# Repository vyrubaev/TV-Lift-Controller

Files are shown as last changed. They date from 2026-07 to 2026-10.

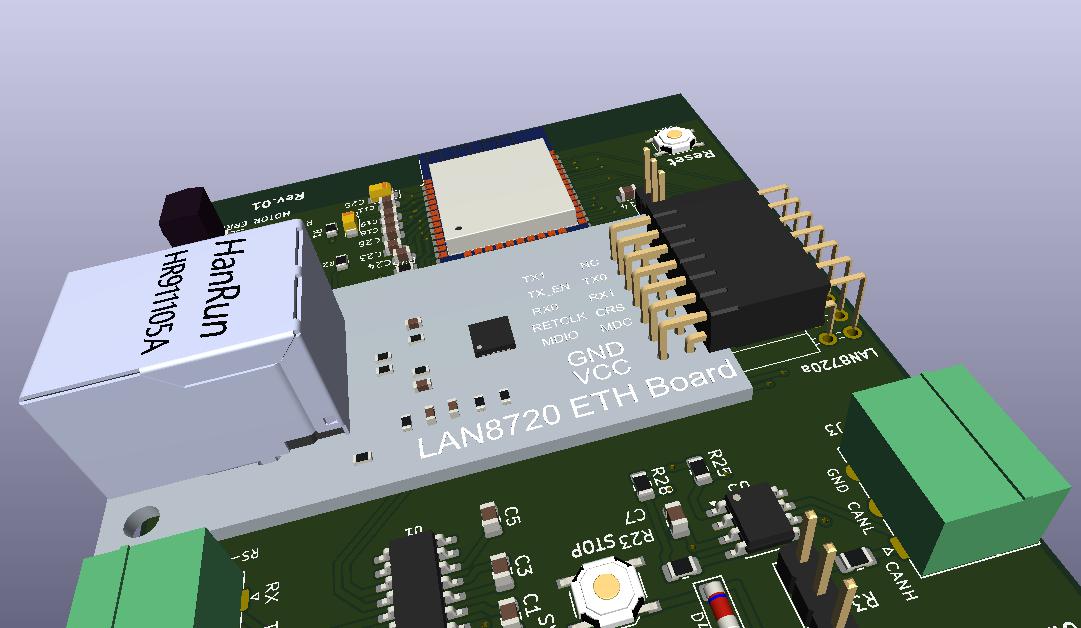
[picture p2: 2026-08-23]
images/network plate.jpg

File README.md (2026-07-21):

# TVLift Controller

Профессиональная платформа управления лифтом для телевизора на базе ESP32.

Проект включает в себя:

- прошивку контроллера ESP32;
- мобильное приложение;
- сервер обновлений и управления;
- веб-панель администратора;
- аппаратную документацию;
- систему удаленного обновления прошивки (OTA — Over-the-Air);
- полную инженерную документацию.

---

# Основные возможности

- управление электроприводом лифта;
- поддержка Wi-Fi и Ethernet;
- первоначальная настройка через Captive Portal;
- безопасное удаленное обновление прошивки;
- хранение настроек во Flash памяти;
- REST API для мобильного приложения;
- журнал событий;
- диагностика устройства;
- поддержка нескольких аппаратных ревизий.

---

# Архитектура проекта

```
TVLift/

├── docs/               Документация
├── firmware/           Прошивка ESP32
├── backend/            Сервер
├── mobile/             Мобильное приложение
├── web-admin/          Панель администратора
├── hardware/           KiCad (схемы и PCB)
├── tools/              Скрипты и утилиты
├── component-library/  Библиотека компонентов
└── README.md
```

---

# Документация

## Архитектура

| Документ | Назначение |
|---|---|
| 00_ProjectVision.md | Цели проекта |
| 01_SystemArchitecture.md | Общая архитектура |
| 02_FirmwareArchitecture.md | Архитектура прошивки |
| 03_StateMachine.md | Конечный автомат |
| 04_API.md | REST API |
| 05_OTA.md | Система обновлений |

---

## Аппаратная часть

| Документ | Назначение |
|---|---|
| Board.md | Описание платы |
| Pinout.md | Назначение выводов |
| Power.md | Система питания |

---

## Библиотека компонентов

В проекте используется собственная библиотека утвержденных компонентов.

Все новые устройства должны использовать компоненты из этой библиотеки, если нет технической причины выбрать другой элемент.

---

# Используемые технологии

## Firmware

- ESP32
- ESP-IDF
- PlatformIO
- C++17

## Backend

- Python
- FastAPI
- PostgreSQL

## Mobile

- Flutter

## Web

- React
- TypeScript

---

# Основные принципы разработки

Проект строится по следующим правилам:

- модульная архитектура;
- минимальная связанность модулей;
- отсутствие глобальных переменных;
- отсутствие динамического выделения памяти в рабочем режиме;
- аппаратная независимость бизнес-логики;
- документирование всех архитектурных решений;
- обязательное код-ревью перед слиянием изменений.

---

# Структура прошивки

Firmware состоит из независимых модулей.

- Boot
- Configuration
- Storage
- Hardware Abstraction Layer (HAL)
- Network Manager
- OTA Manager
- REST API
- Elevator Controller
- Logger
- Diagnostics

---

# Состояния контроллера

Boot

↓

Hardware Init

↓

Load Configuration

↓

Network Connection

↓

Cloud Connection

↓

Ready

↓

Working

↓

Error Recovery

---

# Требования к качеству

- единый стиль кода;
- обязательное документирование публичных интерфейсов;
- отсутствие магических чисел;
- отсутствие дублирования кода;
- обязательные журналы ошибок;
- возможность безопасного восстановления после сбоя.

---

# Версионирование

Используется Semantic Versioning.

MAJOR.MINOR.PATCH

Например

2.4.15

---

# Лицензия

Определяется владельцем проекта.

---

# Статус проекта

🚧 В активной разработке.

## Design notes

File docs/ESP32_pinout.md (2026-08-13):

ESP32-WROOM-32 — карта выводов

**Плата:** TV Lift Controller REV_A  
**Модуль:** ESP32-WROOM-32  
**Источник истины для прошивки:** `BoardConfig`

## Назначение GPIO

| GPIO | Направление | Назначение | Примечание |
|---:|---|---|---|
| 0 | вход | `ETH_RETCLK` | Вход внешнего RMII REF_CLK 50 МГц; strapping-пин. PHY не должен выдавать clock до завершения boot. |
| 1 | выход | `UART_TX_PIN` | UART0 TX / RS-232. Используется также для загрузочных сообщений. |
| 2 | выход | `IR_TRANSMITTER` | Strapping-пин; не подтягивать к +3.3 V при reset. |
| 3 | вход | `UART_RX_PIN` | UART0 RX / RS-232. |
| 4 | вход | `LIMIT_SWITCH_UP_PIN` | Верхний концевик. Обрабатывать аппаратным GPIO-прерыванием. |
| 5 | выход | `CAN_TX_PIN` | Strapping-пин, внешняя подтяжка к +3.3 V допустима и соответствует штатному уровню `1`. |
| 12 | выход | `MOTOR1_PWM` | Strapping-пин MTDI. Во время reset должен оставаться `0`; запрещена внешняя подтяжка к +3.3 V. |
| 13 | вход | `LIMIT_SWITCH_DOWN_PIN` | Нижний концевик. Обрабатывать аппаратным GPIO-прерыванием. |
| 14 | вход | `IR_RECEIVER` | Вход ИК-приёмника. |
| 15 | вход | `CAN_RX_PIN` | Strapping-пин MTDO, внешняя подтяжка к +3.3 V допустима и соответствует штатному уровню `1`. |
| 16 | выход | `MOTOR1_INA` | Направление A драйвера VNH5019. |
| 17 | выход | `MOTOR1_INB` | Направление B драйвера VNH5019. |
| 18 | выход | `ETH_MDIO` | RMII MDIO. |
| 19 | выход | `ETH_TX0` | RMII TXD0. |
| 21 | выход | `ETH_TX_EN` | RMII TX_EN. |
| 22 | выход | `ETH_TX1` | RMII TXD1. |
| 23 | выход | `ETH_MDC` | RMII MDC. |
| 25 | вход | `ETH_RX0` | RMII RXD0. |
| 26 | вход | `ETH_RX1` | RMII RXD1. |
| 27 | вход | `ETH_CRS_DV` | RMII CRS_DV. |
| 32 | вход, ADC | `MOTOR1_CURR_SENS` | Измерение тока двигателя. |
| 33 | вход | `MOTOR1_DIAG` | Авария драйвера VNH5019. Обрабатывать GPIO-прерыванием. |
| 34 | вход | `DRY_CONTACT_DOWN_PIN` | Выход оптопары сухого контакта «вниз». Только вход, внутренней подтяжки нет. |
| 35 | вход | `DRY_CONTACT_UP_PIN` | Выход оптопары сухого контакта «вверх». Только вход, внутренней подтяжки нет. |
| 36 | вход | `ENC_A` | Канал A энкодера. Только вход. |
| 39 | вход | `ENC_B` | Канал B энкодера. Только вход. |

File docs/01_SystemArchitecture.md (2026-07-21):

                  +----------------------+
                  |      Application     |
                  |  (логика устройства) |
                  +----------+-----------+
                             |
      +----------+-----------+-----------+----------+
      |          |           |           |          |
+-----v----+ +---v----+ +----v----+ +----v----+ +---v----+
| Elevator | |Network | | Storage | |   OTA   | | Logger |
+----------+ +--------+ +---------+ +---------+ +--------+
      |           |           |           |
      +-----------+-----------+-----------+
                      |
              +-------v--------+
              |      HAL       |
              | Hardware Layer |
              +-------+--------+
                      |
         +------------+-------------+
         | GPIO I²C SPI UART CAN IR |
         +--------------------------+

---

Полная карта модулей прошивки V.1

Application
│
├── System
│   ├── BootManager
│   ├── TaskManager
│   ├── Watchdog
│   ├── TimeService
│   └── EventBus
│
├── Configuration
│   ├── ConfigManager
│   ├── DeviceConfig
│   ├── NetworkConfig
│   └── UserConfig
│
├── Storage
│   ├── NVS
│   ├── LittleFS
│   └── Backup
│
├── Network
│   ├── NetworkManager
│   ├── WiFiManager
│   ├── EthernetManager
│   ├── DNS
│   ├── DHCP
│   ├── HTTP Client
│   ├── HTTPS Client
│   ├── WebServer
│   └── CaptivePortal
│
├── OTA
│   ├── UpdateManager
│   ├── FirmwareDownloader
│   ├── FirmwareVerifier
│   └── RollbackManager
│
├── Security
│   ├── TLS
│   ├── Certificates
│   ├── DeviceIdentity
│   └── Authentication
│
├── API
│   ├── REST API
│   ├── JSON
│   └── API Dispatcher
│
├── Logger
│   ├── Console
│   ├── FlashLog
│   └── RemoteLog
│
├── Diagnostics
│   ├── SelfTest
│   ├── Statistics
│   ├── MemoryMonitor
│   └── CrashReporter
│
├── Elevator
│   ├── LiftController
│   ├── MotorController
│   ├── SafetyController
│   ├── Calibration
│   ├── Inputs
│   ├── Outputs
│   ├── Position
│   └── Limits
│
└── HAL
    ├── GPIO
    ├── ADC
    ├── PWM
    ├── Timers
    ├── UART
    ├── SPI
    ├── I2C
    ├── CAN
    ├── IR
    ├── Ethernet
    ├── WiFi
    ├── Flash
    └── RTC

    ---

    Полная карта модулей прошивки V.2

    Application
│
├── Core
│
├── Config
│
├── Network
│
├── OTA
│
├── API
│
├── Logger
│
├── Elevator
│
├── Drivers
│
└── HAL

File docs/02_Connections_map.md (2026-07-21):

GPIO5:
    Function:
    Motor Driver Diagnostic Input

    Boot requirement:
    Must be HIGH during reset

    External pull-up required

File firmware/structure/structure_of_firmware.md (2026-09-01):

src/

├── main.cpp

├── Core/
│   ├── Core.h
│   └── Core.cpp

├── Config/
│   ├── BoardConfig.h
│   └── DeviceConfig.h

├── Logger/
│   ├── Logger.h
│   └── Logger.cpp

├── Elevator/
│   ├── Elevator.h
│   └── Elevator.cpp

├── Drivers/
│   ├── Motor.h
│   └── Motor.cpp

├── Network/
│
├── OTA/
|
│
└── API/

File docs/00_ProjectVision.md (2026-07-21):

# TVLift Controller

# Project Vision

**Версия документа:** 1.0

**Статус:** Draft

**Дата:** 2026-07-20

---

# 1. Назначение проекта

TVLift Controller — это интеллектуальный контроллер управления механизмом подъема и опускания телевизора, построенный на базе микроконтроллера ESP32.

Устройство предназначено для управления электрическими приводами телевизионных лифтов, мебели с автоматическим открыванием, подъемных механизмов и других электромеханических систем.

Проект ориентирован не на создание единичного устройства, а на разработку масштабируемой платформы, которая может использоваться в нескольких линейках изделий.

---

# 2. Цели проекта

Основные цели разработки:

- создать надежную промышленную прошивку;
- обеспечить возможность удаленного обновления программного обеспечения;
- максимально упростить первоначальную настройку устройства;
- обеспечить высокую отказоустойчивость;
- сделать архитектуру независимой от конкретной аппаратной ревизии;
- обеспечить возможность дальнейшего расширения функциональности без переписывания существующего кода.

---

# 3. Основные требования

Контроллер должен:

- работать круглосуточно без перезагрузок;
- автоматически восстанавливать работу после отключения питания;
- автоматически восстанавливать соединение с сетью;
- поддерживать безопасное обновление прошивки;
- сохранять пользовательские настройки;
- иметь встроенные средства диагностики.

---

# 4. Основные возможности

Первая версия должна поддерживать:

- Wi-Fi;
- Ethernet;
- первоначальную настройку через Captive Portal;
- REST API;
- удаленное обновление прошивки (OTA);
- управление приводом;
- хранение конфигурации;
- журнал событий;
- удаленную диагностику.

---

# 5. Требования к надежности

Контроллер является частью исполнительного механизма.

Ошибки программного обеспечения могут привести к:

- остановке механизма;
- повреждению оборудования;
- ухудшению пользовательского опыта.

Поэтому:

- никакая ошибка не должна приводить к повреждению оборудования;
- после любой программной ошибки устройство должно автоматически восстанавливаться;
- критические ошибки должны фиксироваться в журнале.

---

# 6. Безопасность

Контроллер обязан обеспечивать безопасную работу оборудования.

Запрещается:

- одновременное включение противоположных направлений двигателя;
- выполнение потенциально опасных команд при обнаружении ошибок;
- установка неподписанной или поврежденной прошивки.

Все сетевые соединения должны использовать защищенные механизмы передачи данных.

---

# 7. Производительность

Контроллер должен:

- быстро загружаться после подачи питания;
- обеспечивать мгновенную реакцию на команды управления;
- выполнять сетевые операции в фоновом режиме;
- не блокировать управление механизмом во время работы сети или OTA.

---

# 8. Масштабируемость

Архитектура должна позволять без существенных изменений добавлять:

- новые аппаратные ревизии;
- новые исполнительные механизмы;
- новые интерфейсы связи;
- новые мобильные приложения;
- облачные сервисы;
- дополнительные датчики.

---

# 9. Поддерживаемые интерфейсы

На первом этапе предусматривается поддержка:

- Wi-Fi IEEE 802.11 b/g/n;
- Ethernet;
- UART (Universal Asynchronous Receiver/Transmitter);
- I²C (Inter-Integrated Circuit);
- SPI (Serial Peripheral Interface);
- CAN (Controller Area Network);
- инфракрасного приемника;
- инфракрасного передатчика.

Архитектура должна позволять подключение дополнительных интерфейсов без изменения существующей логики.

---

# 10. Архитектурные принципы

Проект разрабатывается в соответствии со следующими принципами:

- модульность;
- слабая связанность компонентов;
- высокая читаемость кода;
- единый стиль разработки;
- разделение аппаратной и прикладной логики;
- отсутствие скрытых зависимостей между модулями;
- документирование всех публичных интерфейсов.

---

# 11. Принципы разработки

Каждый новый модуль должен:

- иметь четко определенную ответственность;
- иметь минимальное количество зависимостей;
- иметь документированный интерфейс;
- быть пригодным для повторного использования;
- быть максимально независимым от остальных компонентов системы.

---

# 12. Принципы тестирования

Перед включением в основную ветку проекта каждый модуль должен пройти:

- модульное тестирование;
- интеграционное тестирование;
- тестирование на реальном оборудовании.

---

# 13. Поддерживаемые платформы

Основная аппаратная платформа:

- ESP32.

В дальнейшем должна сохраняться возможность перехода на:

- ESP32-S3;
- ESP32-C6;
- другие совместимые микроконтроллеры.

---

# 14. Долгосрочная стратегия

Проект рассматривается как единая программная платформа.

В дальнейшем планируется разработка:

- контроллеров телевизионных лифтов;
- контроллеров автоматических штор;
- контроллеров мебели;
- контроллеров ворот;
- контроллеров освещения;
- контроллеров вентиляции;
- универсальных модулей ввода-вывода.

Все устройства должны использовать общую архитектуру, единый стиль разработки и максимально возможное количество повторно используемых модулей.

---

# 15. Критерии успеха проекта

Проект считается успешным, если:

- устройство стабильно работает в течение длительного времени;
- обновление прошивки выполняется без участия пользователя;
- первоначальная настройка занимает не более нескольких минут;
- добавление новых функций не требует изменения существующих модулей;
- новая аппаратная ревизия поддерживается с минимальными изменениями программного обеспечения.

---

# 16. Основной принцип проекта

**Надежность важнее функциональности.**

Любая новая возможность должна добавляться только в том случае, если она не снижает надежность, безопасность и сопровождаемость системы.

---

# 17. Основные сценарии использования (Use Cases)

## Сценарий 1. Первое включение устройства

1. Пользователь подает питание.
2. Контроллер выполняет самодиагностику.
3. Проверяет наличие сохраненной конфигурации.
4. Если конфигурации нет:
   - запускает собственную точку доступа Wi-Fi;
   - автоматически открывает страницу первоначальной настройки (Captive Portal).
5. Пользователь выбирает тип подключения:
   - Wi-Fi;
   - Ethernet.
6. После сохранения параметров контроллер перезагружается.
7. Выполняется подключение к сети.
8. Контроллер регистрируется на сервере.
9. Устройство готово к работе.

---

## Сценарий 2. Обычная работа

1. После включения устройство автоматически подключается к сети.
2. Проверяет наличие новой версии прошивки.
3. Переходит в рабочий режим.
4. Выполняет команды пользователя.
5. Передает диагностическую информацию.
6. Контролирует состояние оборудования.

---

## Сценарий 3. Потеря сети

1. Контроллер обнаруживает потерю соединения.
2. Продолжает управлять механизмом локально.
3. Периодически пытается восстановить соединение.
4. После восстановления автоматически синхронизируется с сервером.

---

## Сценарий 4. Смена Wi-Fi

1. Контроллер не может подключиться к сохраненной сети.
2. Выполняет несколько попыток подключения.
3. Если подключение не удалось:
   - запускает режим первоначальной настройки.
4. Пользователь вводит новые параметры сети.
5. Настройки сохраняются.
6. Контроллер автоматически подключается к новой сети.

---

## Сценарий 5. Обновление прошивки

1. Контроллер проверяет сервер обновлений.
2. Если доступна новая версия:
   - скачивает прошивку;
   - проверяет контрольную сумму;
   - записывает новую прошивку во второй OTA-раздел.
3. Выполняется перезагрузка.
4. Если новая прошивка успешно запустилась — она становится основной.
5. Если запуск завершился ошибкой — выполняется автоматический откат.

---

## Сценарий 6. Отключение питания

1. Питание пропадает.
2. После восстановления питания контроллер автоматически загружается.
3. Восстанавливает сохраненную конфигурацию.
4. Подключается к сети.
5. Возвращается в рабочий режим без участия пользователя.

---

## Сценарий 7. Управление устройством

Пользователь может управлять устройством:

- локальными кнопками;
- мобильным приложением;
- веб-интерфейсом;
- REST API.

Независимо от способа управления логика работы устройства должна быть одинаковой.

---

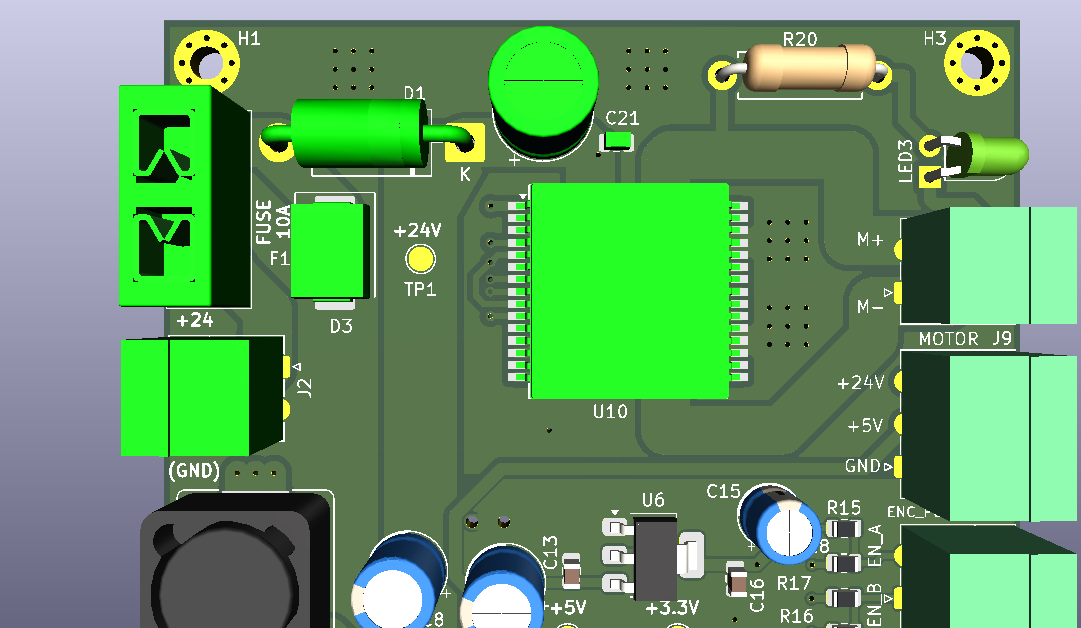
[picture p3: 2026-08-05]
hardware/TV_Lift_Kicad files/controller_Tv_Lift.png

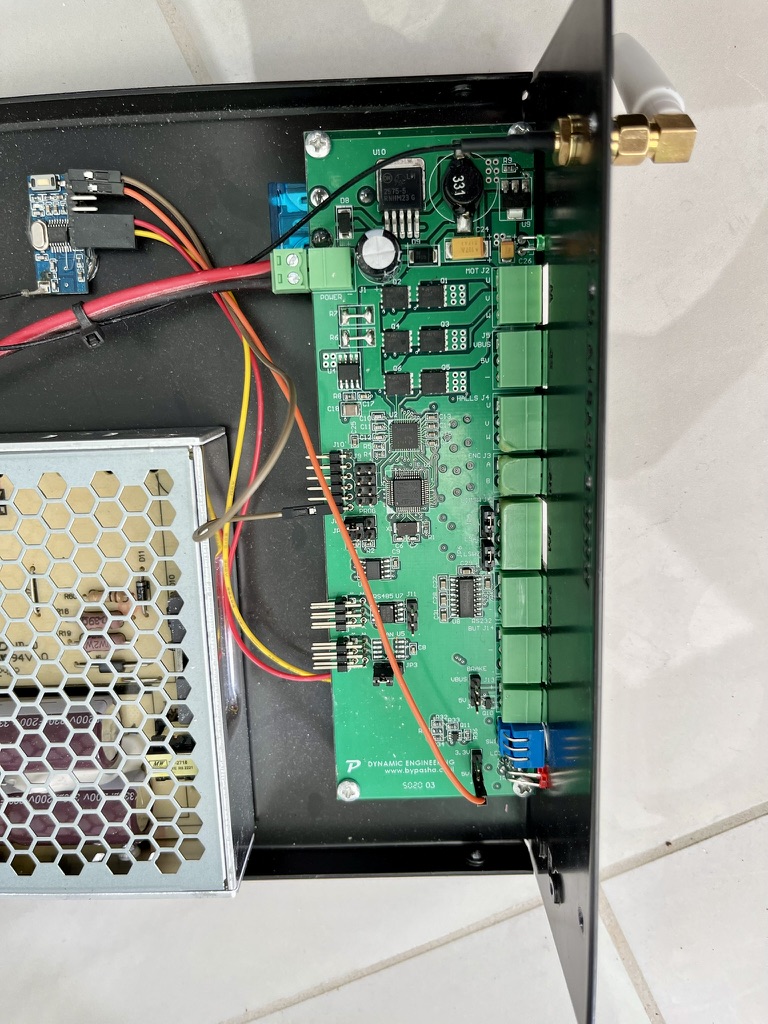
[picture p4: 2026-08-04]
images/202FE293-F63E-4EFC-A8E8-066FBEF5A6CB_1_105_c.jpeg

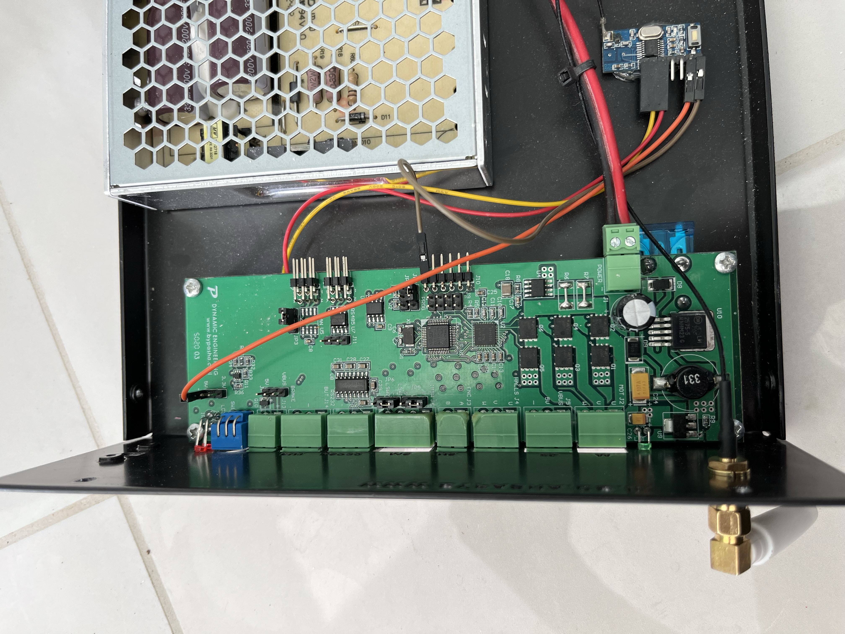
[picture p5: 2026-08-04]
images/плата.jpg

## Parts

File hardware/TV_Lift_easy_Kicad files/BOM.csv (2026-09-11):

Reference | Qty | Value | DNP | Exclude from BOM | Exclude from Board | Footprint | Datasheet | Sim.Pins | Sim.Device | Описание | #
C1,C2,C3,C4,C5,C7,C9,C11,C13,C14,C16,C17,C21,C23,C26 | 15 | 100 nF 50V |  |  |  | Capacitor_SMD:C_0805_2012Metric |  |  |  | C49678 | 1
C6,C25 | 2 | C7171 |  |  |  | Capacitor_Tantalum_SMD:CP_EIA-3216-18_Kemet-A |  |  |  | 10 uF 16V | 2
C8 | 1 | C46550473 |  |  |  | Capacitor_SMD:CP_Elec_10x10 |  |  |  | 220 uF 50V Low ESR | 3
C10 | 1 | C19702 |  |  |  | Capacitor_SMD:C_0603_1608Metric |  |  |  | 10 uF 10V | 4
C12 | 1 | C25503905 |  |  |  | Capacitor_SMD:CP_Elec_6.3x7.7 |  |  |  | 220 uF 16V | 5
C15,C22 | 2 | C16133 |  |  |  | Capacitor_Tantalum_SMD:CP_EIA-3528-21_Kemet-B_HandSolder |  |  |  | 100 uF 6,3V | 6
C18,C19,C24 | 3 | 1 nF 50V |  |  |  | Capacitor_SMD:C_0805_2012Metric |  |  |  |  | 7
C20 | 1 | 1000 uF 50V |  |  |  | Capacitor_THT:CP_Radial_D8.0mm_P3.50mm |  |  |  |  | 8
D1 | 1 | 20SQ045 |  |  |  | Diode_THT:D_DO-201AD_P15.24mm_Horizontal | http://www.vishay.com/docs/88526/1n5820.pdf |  |  |  | 9
D3 | 1 | SMCJ26A |  |  |  | Diode_SMD:D_SMC | https://www.vishay.com/docs/88303/15smc.pdf |  |  | 1500W unidirectional TVS diode, SMC (DO-201AB) | 10
D4,D5 | 2 | LL4148 |  |  |  | Diode_SMD:D_MiniMELF | http://www.vishay.com/docs/85557/ll4148.pdf | 1=K 2=A | D | 100V 0.15A standard switching diode, MiniMELF | 11
D6 | 1 | KT-0805W |  |  |  | LED_SMD:LED_0805_2012Metric |  | 1=K 2=A |  | Light emitting diod white | 12
D7 | 1 | KT-0805G |  |  |  | LED_SMD:LED_0805_2012Metric |  | 1=K 2=A |  | Light emitting diode green | 13
D8 | 1 | SS34 |  |  |  | Diode_SMD:D_SMA | https://www.vishay.com/docs/88751/ss32.pdf |  |  | 40V 3A Schottky Diode, SMA | 14
F1 | 1 | C492610 |  |  |  | Fuse:Fuseholder_XF-506P_mini_blade_C492610 |  |  |  | C492610 | 15
J1 | 1 | C54620381 |  |  |  | Connector_PinSocket_2.54mm:PinSocket_2x07_P2.54mm_Vertical |  |  |  | C54620381 | 16
J2 | 1 | 1836189 |  |  |  | Connector_Phoenix_MC_HighVoltage:PhoenixContact_MC_1,5_2-G-5.08_1x02_P5.08mm_Horizontal | 1836189 |  |  | POWER 24V | 17
J3,J5,J6,J11 | 4 | 1844223 |  |  |  | Connector_Phoenix_MC:PhoenixContact_MC_1,5_3-G-3.5_1x03_P3.50mm_Horizontal |  |  |  | CAN_BUS,CONN_RS232,DRY CONTACT UP DOWN,ENCODER_POWER | 18
J4,J9,J10 | 3 | 1844210 |  |  |  | Connector_Phoenix_MC:PhoenixContact_MC_1,5_2-G-3.5_1x02_P3.50mm_Horizontal |  |  |  | CONN_IR_OUT,ENCODER,MOTOR_OUT | 19
J7 | 1 | 1844236 |  |  |  | Connector_Phoenix_MC:PhoenixContact_MC_1,5_4-G-3.5_1x04_P3.50mm_Horizontal |  |  |  | M1 LIMIT UP DOWN | 20
J8,J12,JP3,JP4 | 4 | C5360899 |  |  |  | Connector_PinHeader_2.54mm:PinHeader_1x03_P2.54mm_Vertical |  |  |  | C5360899,DRY_CONTACT,Signal PWR | 21
L1 | 1 | C55109499 |  |  |  | Inductor_SMD:L_APV_ANR6045 |  |  |  | C55109499 | 22
LED1 | 1 | KT-0805Y |  |  |  | LED_SMD:LED_0805_2012Metric |  |  |  | LED_YELLOW_F3_POWER | 23
LED2 | 1 | C84256 |  |  |  | LED_SMD:LED_0805_2012Metric |  | 1=K 2=A |  | Light emitting diode NCD0805R1 | 24
Q2 | 1 | C105432 |  |  |  | Package_TO_SOT_SMD:SOT-23 | kicad-embed://C105432.pdf | 1=B 2=E 3=C | PNP | -0.2A Ic, -40V Vce, Small Signal PNP Transistor, SOT-23 | 25
R1,R4,R6,R7,R11,R12,R13,R17,R18,R25,R27,R28 | 12 | 10k |  |  |  | Resistor_SMD:R_0805_2012Metric |  |  |  |  | 26
R2,R9,R10,R15,R16 | 5 | 100 |  |  |  | Resistor_SMD:R_0805_2012Metric |  |  |  |  | 27
R3 | 1 | 120 |  |  |  | Resistor_SMD:R_0805_2012Metric |  |  |  |  | 28
R5 | 1 | 2.2k |  |  |  | Resistor_SMD:R_0805_2012Metric |  |  |  |  | 29
R8,R14,R19,R26 | 4 | 470 |  |  |  | Resistor_SMD:R_0805_2012Metric |  |  |  |  | 30
R20 | 1 | C17936 |  |  |  | Resistor_SMD:R_1206_3216Metric |  |  |  | resistor 4,7 кОм 0.250 Вт | 31
R21,R23 | 2 | 1k |  |  |  | Resistor_SMD:R_0805_2012Metric |  |  |  |  | 32
R22 | 1 | 47 |  |  |  | Resistor_SMD:R_1206_3216Metric |  |  |  |  | 33
SW1,SW2,SW3,SW4 | 4 | TS-1187A-BAB |  |  |  | Button_Switch_SMD:SW_Push_1P1T_XKB_TS-1187A |  |  |  | DOWN,RESET,STOP,UP | 34
U1 | 1 | MAX3232 |  |  |  | Package_SO:SOIC-16_3.9x9.9mm_P1.27mm | https://datasheets.maximintegrated.com/en/ds/MAX3222-MAX3241.pdf |  |  |  | 35
U2 | 1 | C145345 |  |  |  | OptoDevice:Vishay_MOLD-3Pin | http://www.vishay.com/docs/82669/tsop32s40f.pdf |  |  |  | 36
U3 | 1 | SN65HVD230 |  |  |  | Package_SO:SOIC-8_3.9x4.9mm_P1.27mm | http://www.ti.com/lit/ds/symlink/sn65hvd230.pdf |  |  |  | 37
U4 | 1 | ESP32-WROOM-32E-N16 |  |  |  | RF_Module:ESP32-WROOM-32 | https://www.espressif.com/sites/default/files/documentation/esp32-wroom-32_datasheet_en.pdf |  |  | ESP32-WROOM-32E-N16 | 38
U5 | 1 | LM2596S-5 |  |  |  | Package_TO_SOT_SMD:TO-263-5_TabPin3 | http://www.ti.com/lit/ds/symlink/lm2596.pdf |  |  |  | 39
U6 | 1 | AMS1117-3.3 |  |  |  | Package_TO_SOT_SMD:SOT-223-3_TabPin2 | http://www.advanced-monolithic.com/pdf/ds1117.pdf |  |  | 1A Low Dropout regulator, positive, 3.3V fixed output, SOT-223 | 40
U10 | 1 | VNH5019ATR-E |  |  |  | Package_SO:ST_MultiPowerSO-30 | https://www.st.com/resource/en/datasheet/vnh5019a-e.pdf |  |  | VNH5019ATR-E | 41

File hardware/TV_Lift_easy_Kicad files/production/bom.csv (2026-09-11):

Designator | Footprint | Quantity | Value | LCSC Part #
C1, C11, C13, C14, C16, C17, C2, C21, C23, C26, C3, C4, C5, C7, C9 | 0805 | 15 | 100 nF 50V
C10 | 0603 | 1 | C19702
C12 | CP_Elec_6.3x7.7 | 1 | C25503905
C15, C22 | CP_EIA-3528-21_Kemet-B_HandSolder | 2 | C16133
C18, C19, C24 | 0805 | 3 | 1 nF 50V
C20 | CP_Radial_D8.0mm_P3.50mm | 1 | 1000 uF 50V
C25, C6 | CP_EIA-3216-18_Kemet-A | 2 | C7171
C8 | CP_Elec_10x10 | 1 | C46550473
D1 | D_DO-201AD_P15.24mm_Horizontal | 1 | 20SQ045
D3 | D_SMC | 1 | SMCJ26A
D4, D5 | D_MiniMELF | 2 | LL4148
D6 | 0805 | 1 | KT-0805W
D7 | 0805 | 1 | KT-0805G
D8 | D_SMA | 1 | SS34
F1 | Fuseholder_XF-506P_mini_blade_C492610 | 1 | C492610
J1 | PinSocket_2x07_P2.54mm_Vertical | 1 | C54620381
J10, J4, J9 | PhoenixContact_MC_1,5_2-G-3.5_1x02_P3.50mm_Horizontal | 3 | 1844210
J11, J3, J5, J6 | PhoenixContact_MC_1,5_3-G-3.5_1x03_P3.50mm_Horizontal | 4 | 1844223
J12, J8, JP3, JP4 | PinHeader_1x03_P2.54mm_Vertical | 4 | C5360899
J2 | PhoenixContact_MC_1,5_2-G-5.08_1x02_P5.08mm_Horizontal | 1 | 1836189
J7 | PhoenixContact_MC_1,5_4-G-3.5_1x04_P3.50mm_Horizontal | 1 | 1844236
L1 | L_APV_ANR6045 | 1 | C55109499
LED1 | 0805 | 1 | KT-0805Y
LED2 | 0805 | 1 | C84256
Q2 | SOT-23 | 1 | C105432
R1, R11, R12, R13, R17, R18, R25, R27, R28, R4, R6, R7 | 0805 | 12 | 10k
R10, R15, R16, R2, R9 | 0805 | 5 | 100
R14, R19, R26, R8 | 0805 | 4 | 470
R20 | 1206 | 1 | C17936
R21, R23 | 0805 | 2 | 1k
R22 | 1206 | 1 | 47
R3 | 0805 | 1 | 120
R5 | 0805 | 1 | 2.2k
SW1, SW2, SW3, SW4 | SW_Push_1P1T_XKB_TS-1187A | 4 | TS-1187A-BAB
U1 | SOIC-16_3.9x9.9mm_P1.27mm | 1 | MAX3232
U10 | ST_MultiPowerSO-30 | 1 | VNH5019ATR-E
U2 | Vishay_MOLD-3Pin | 1 | C145345
U3 | SOIC-8_3.9x4.9mm_P1.27mm | 1 | SN65HVD230
U4 | ESP32-WROOM-32 | 1 | ESP32-WROOM-32E-N16
U5 | TO-263-5_TabPin3 | 1 | LM2596S-5
U6 | SOT-223-3_TabPin2 | 1 | AMS1117-3.3

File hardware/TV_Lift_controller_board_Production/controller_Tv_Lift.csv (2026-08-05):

controller_Tv_Lift
Reference | Qty | Value | DNP | Exclude from BOM | Exclude from Board | Datasheet | Описание | Описание
C1,C2,C3,C4,C5,C7,C11,C13,C14,C17,C22,C23 | 12 | 0.1 uF 16V |  |  |  | Capacitor_SMD:C_0805_2012Metric
C6 | 1 | 10 uF 16V |  |  |  | Capacitor_THT:CP_Radial_D5.0mm_P2.00mm
C8 | 1 | 220 uF 50V Low ESR |  |  |  | Capacitor_THT:CP_Radial_D6.3mm_P2.50mm |  | 220 uF 50V Low ESR
C9,C21 | 2 | 0.1 uF 50V |  |  |  | Capacitor_SMD:C_0805_2012Metric
C10 | 1 | 10 uF 10V |  |  |  | Capacitor_THT:CP_Radial_D5.0mm_P2.00mm
C12 | 1 | 150 uF 16V |  |  |  | Capacitor_THT:CP_Radial_D6.3mm_P2.50mm
C15 | 1 | 150 uF 10V |  |  |  | Capacitor_THT:CP_Radial_D5.0mm_P2.00mm
C16 | 1 | 0.1 uF 10V |  |  |  | Capacitor_SMD:C_0805_2012Metric
C18,C19 | 2 | 1 nF 16V |  |  |  | Capacitor_SMD:C_0805_2012Metric
C20 | 1 | 1000 uF 50V |  |  |  | Capacitor_THT:CP_Radial_D8.0mm_P3.50mm
D1 | 1 | 20SQ045 |  |  |  | Diode_THT:D_DO-201AD_P15.24mm_Horizontal | http://www.vishay.com/docs/88526/1n5820.pdf | Schottky Barrier Diode, 20A, 45V, Low Forward Voltage, Through-Hole (THT), Case DO-201AD / P600 (P=15.24mm Horizontal). STRICT MATCH REQUIRED!
D2 | 1 | 1N5819 |  |  |  | Diode_THT:D_DO-41_SOD81_P10.16mm_Horizontal | http://www.vishay.com/docs/88525/1n5817.pdf
D3 | 1 | SMCJ26A |  |  |  | Diode_SMD:D_SMC | https://www.vishay.com/docs/88303/15smc.pdf | TVS Diode 26V (or 28V) 1500W Unidirectional, SMD Case SMC (DO-214AB)
D4,D5 | 2 | LL4148 |  |  |  | Diode_SMD:D_MiniMELF | http://www.vishay.com/docs/85557/ll4148.pdf | 100V 0.15A standard switching diode, MiniMELF
F1 | 1 | Fuse_Mini_10A |  |  |  | Fuse:Fuseholder_Blade_Mini_Keystone_3568 |  | PCB Fuse Clip/Holder for Automotive MINI Blade Fuse (ATM/APM standard), Through-Hole THT, Phosphor Bronze Tin Plated, Max 15A. DO NOT install fuse wire, holder clips only!
J1 | 1 | socket LAN8720a |  |  |  | Connector_PinSocket_2.54mm:PinSocket_2x07_P2.54mm_Horizontal |  | 2.54mm Pitch Female Header, Dual Row, Right-Angle (Horizontal), 2x7 Pin, PLASTIC ELEVATED HEIGHT (SPACER): 3.5mm, Total Pin Length 11.5mm, Gold Plated. STRICT MATCH REQUIRED!
J2 | 1 | POWER 24V |  |  |  | Connector_Phoenix_MC_HighVoltage:PhoenixContact_MC_1,5_2-G-5.08_1x02_P5.08mm_Horizontal
J3 | 1 | CAN_bus |  |  |  | Connector_Phoenix_MC:PhoenixContact_MC_1,5_3-G-3.5_1x03_P3.50mm_Horizontal
J4 | 1 | ENCODER |  |  |  | Connector_Phoenix_MC:PhoenixContact_MC_1,5_2-G-3.5_1x02_P3.50mm_Horizontal
J5 | 1 | ENCODER_POWER |  |  |  | Connector_Phoenix_MC:PhoenixContact_MC_1,5_3-G-3.5_1x03_P3.50mm_Horizontal
J6 | 1 | CONN_RS232 |  |  |  | Connector_Phoenix_MC:PhoenixContact_MC_1,5_3-G-3.5_1x03_P3.50mm_Horizontal
J7 | 1 | M1 LIMIT UP DOWN |  |  |  | Connector_Phoenix_MC:PhoenixContact_MC_1,5_4-G-3.5_1x04_P3.50mm_Horizontal
J8 | 1 | Signal PWR |  |  |  | Connector_PinHeader_2.54mm:PinHeader_1x03_P2.54mm_Vertical |  | Generic connector, single row, 01x03, script generated
J9 | 1 | MOTOR_OUT |  |  |  | Connector_Phoenix_MC:PhoenixContact_MC_1,5_2-G-3.5_1x02_P3.50mm_Horizontal
J10 | 1 | CONN_IR_OUT |  |  |  | Connector_Phoenix_MC:PhoenixContact_MC_1,5_2-G-3.5_1x02_P3.50mm_Horizontal
J11 | 1 | DRY CONTACT UP DOWN |  |  |  | Connector_Phoenix_MC:PhoenixContact_MC_1,5_3-G-3.5_1x03_P3.50mm_Horizontal
J12 | 1 | DRY CONTACT |  |  |  | Connector_PinHeader_2.54mm:PinHeader_1x03_P2.54mm_Vertical |  | Generic connector, single row, 01x03, script generated
JP1 | 1 | CAN_Jumper |  |  |  | Connector_PinHeader_2.54mm:PinHeader_1x02_P2.54mm_Vertical
JP2 | 1 | FIRMWARE_Jumper |  |  |  | Connector_PinHeader_2.54mm:PinHeader_1x02_P2.54mm_Vertical
L1 | 1 | 68 uH |  |  |  | Inductor_SMD:L_Bourns_SRR1260
LED1 | 1 | LED_GREEN_F3 |  |  |  | LED_THT:LED_D3.0mm_Horizontal_O1.27mm_Z2.0mm |  | LED_GREEN_F3_POWER
LED2 | 1 | LED_RED_F3 |  |  |  | LED_THT:LED_D3.0mm_Horizontal_O1.27mm_Z6.0mm |  | LED_RED_F3_ERROR1
LED3 | 1 | LED_Dual_Bidirectional_GREEN_BLUE |  |  |  | LED_THT:LED_D3.0mm_Horizontal_O1.27mm_Z6.0mm |  | 3mm Bi-directional Two-Color LED, Green/Blue, 2-Pin (Bi-polar / Anti-parallel connection), Luminous Intensity Standard, Clear/Diffused. STRICT MATCH REQUIRED!
Q1 | 1 | 2N3904 |  |  |  | Package_TO_SOT_THT:TO-92_Inline | https://www.onsemi.com/pub/Collateral/2N3903-D.PDF | 0.2A Ic, 40V Vce, Small Signal NPN Transistor, TO-92
R1,R4,R6,R7,R11,R12,R13,R17,R18,R24,R25,R27 | 12 | 10k |  |  |  | Resistor_SMD:R_0805_2012Metric
R2,R9,R10,R15,R16 | 5 | 100 |  |  |  | Resistor_SMD:R_0805_2012Metric
R3 | 1 | 120 |  |  |  | Resistor_SMD:R_0805_2012Metric
R5 | 1 | 2.2k |  |  |  | Resistor_SMD:R_0805_2012Metric
R8,R14,R19,R26 | 4 | 470 |  |  |  | Resistor_SMD:R_0805_2012Metric |  | Thick Film Resistor, 470 Ohm, SMD Size 0805, 0.125W, Precision ±1%. Connected to clean signal GND.
R20 | 1 | 2.4k |  |  |  | Resistor_THT:R_Axial_DIN0411_L9.9mm_D3.6mm_P12.70mm_Horizontal |  | resistor power 0.5-1 W
R21,R23 | 2 | 1k |  |  |  | Resistor_SMD:R_0805_2012Metric
R22 | 1 | 47 |  |  |  | Resistor_SMD:R_1206_3216Metric |  | Thick Film Resistor, 47 Ohm, SMD SIZE 1206 (3216 Metric), Power 0.25W (1/4W), ±5%. DO NOT substitute with 0805 or 0603 size due to power dissipation!
SW1 | 1 | UP |  |  |  | Button_Switch_THT:SW_PUSH_6mm |  | Push button switch, generic, two pins
SW2 | 1 | DOWN |  |  |  | Button_Switch_THT:SW_PUSH_6mm |  | Push button switch, generic, two pins
SW3 | 1 | STOP |  |  |  | Button_Switch_THT:SW_PUSH_6mm |  | Push button switch, generic, two pins
SW4 | 1 | Reset |  |  |  | Button_Switch_THT:SW_PUSH_6mm |  | Push button switch, generic, two pins
TP1 | 1 | +24V |  |  |  | TestPoint:TestPoint_Pad_D2.0mm |  | test point
TP2 | 1 | +5V |  |  |  | TestPoint:TestPoint_Pad_D2.0mm |  | test point
TP3 | 1 | +3V |  |  |  | TestPoint:TestPoint_Pad_D2.0mm |  | test point
U1 | 1 | MAX3232 |  |  |  | Package_SO:SOIC-16_3.9x9.9mm_P1.27mm | https://datasheets.maximintegrated.com/en/ds/MAX3222-MAX3241.pdf
U2 | 1 | TSOP32S40F |  |  |  | OptoDevice:Vishay_MOLD-3Pin | http://www.vishay.com/docs/82669/tsop32s40f.pdf
U3 | 1 | SN65HVD230 |  |  |  | Package_SO:SOIC-8_3.9x4.9mm_P1.27mm | http://www.ti.com/lit/ds/symlink/sn65hvd230.pdf
U4 | 1 | ESP32-WROOM-32 |  |  |  | RF_Module:ESP32-WROOM-32 | https://www.espressif.com/sites/default/files/documentation/esp32-wroom-32_datasheet_en.pdf
U5 | 1 | LM2596S-5 |  |  |  | Package_TO_SOT_SMD:TO-263-5_TabPin3 | http://www.ti.com/lit/ds/symlink/lm2596.pdf
U6 | 1 | AMS1117-3.3 |  |  |  | Package_TO_SOT_SMD:SOT-223-3_TabPin2 | http://www.advanced-monolithic.com/pdf/ds1117.pdf
U7,U8 | 2 | PC817 |  |  |  | Package_DIP:DIP-4_W7.62mm | http://www.soselectronic.cz/a_info/resource/d/pc817.pdf | Isolated DC-DC Converter, 5V Input to 5V Output, 1 Watt, SIP-4 package, Isolation 1.5kV DC.
U9 | 1 | NCS1S1205SC |  |  |  | Converter_DCDC:Converter_DCDC_Murata_NCS1SxxxxSC_THT | https://power.murata.com/data/power/ncl/kdc_ncs1.pdf
U10 | 1 | VNH5019A-E |  |  |  | Package_SO:ST_MultiPowerSO-30 | https://www.st.com/resource/en/datasheet/vnh5019a-e.pdf

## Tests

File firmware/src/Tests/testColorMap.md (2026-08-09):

пины подтянуты к питанию !
при размыкании питания происходит событие 

бело-синий - dry contact FORWARD
синий      - dry contact REVERSE

коричневый       - FORWARD LIMIT SWITCH
бело- коричневый - REVERSE LIMIT SWITCH

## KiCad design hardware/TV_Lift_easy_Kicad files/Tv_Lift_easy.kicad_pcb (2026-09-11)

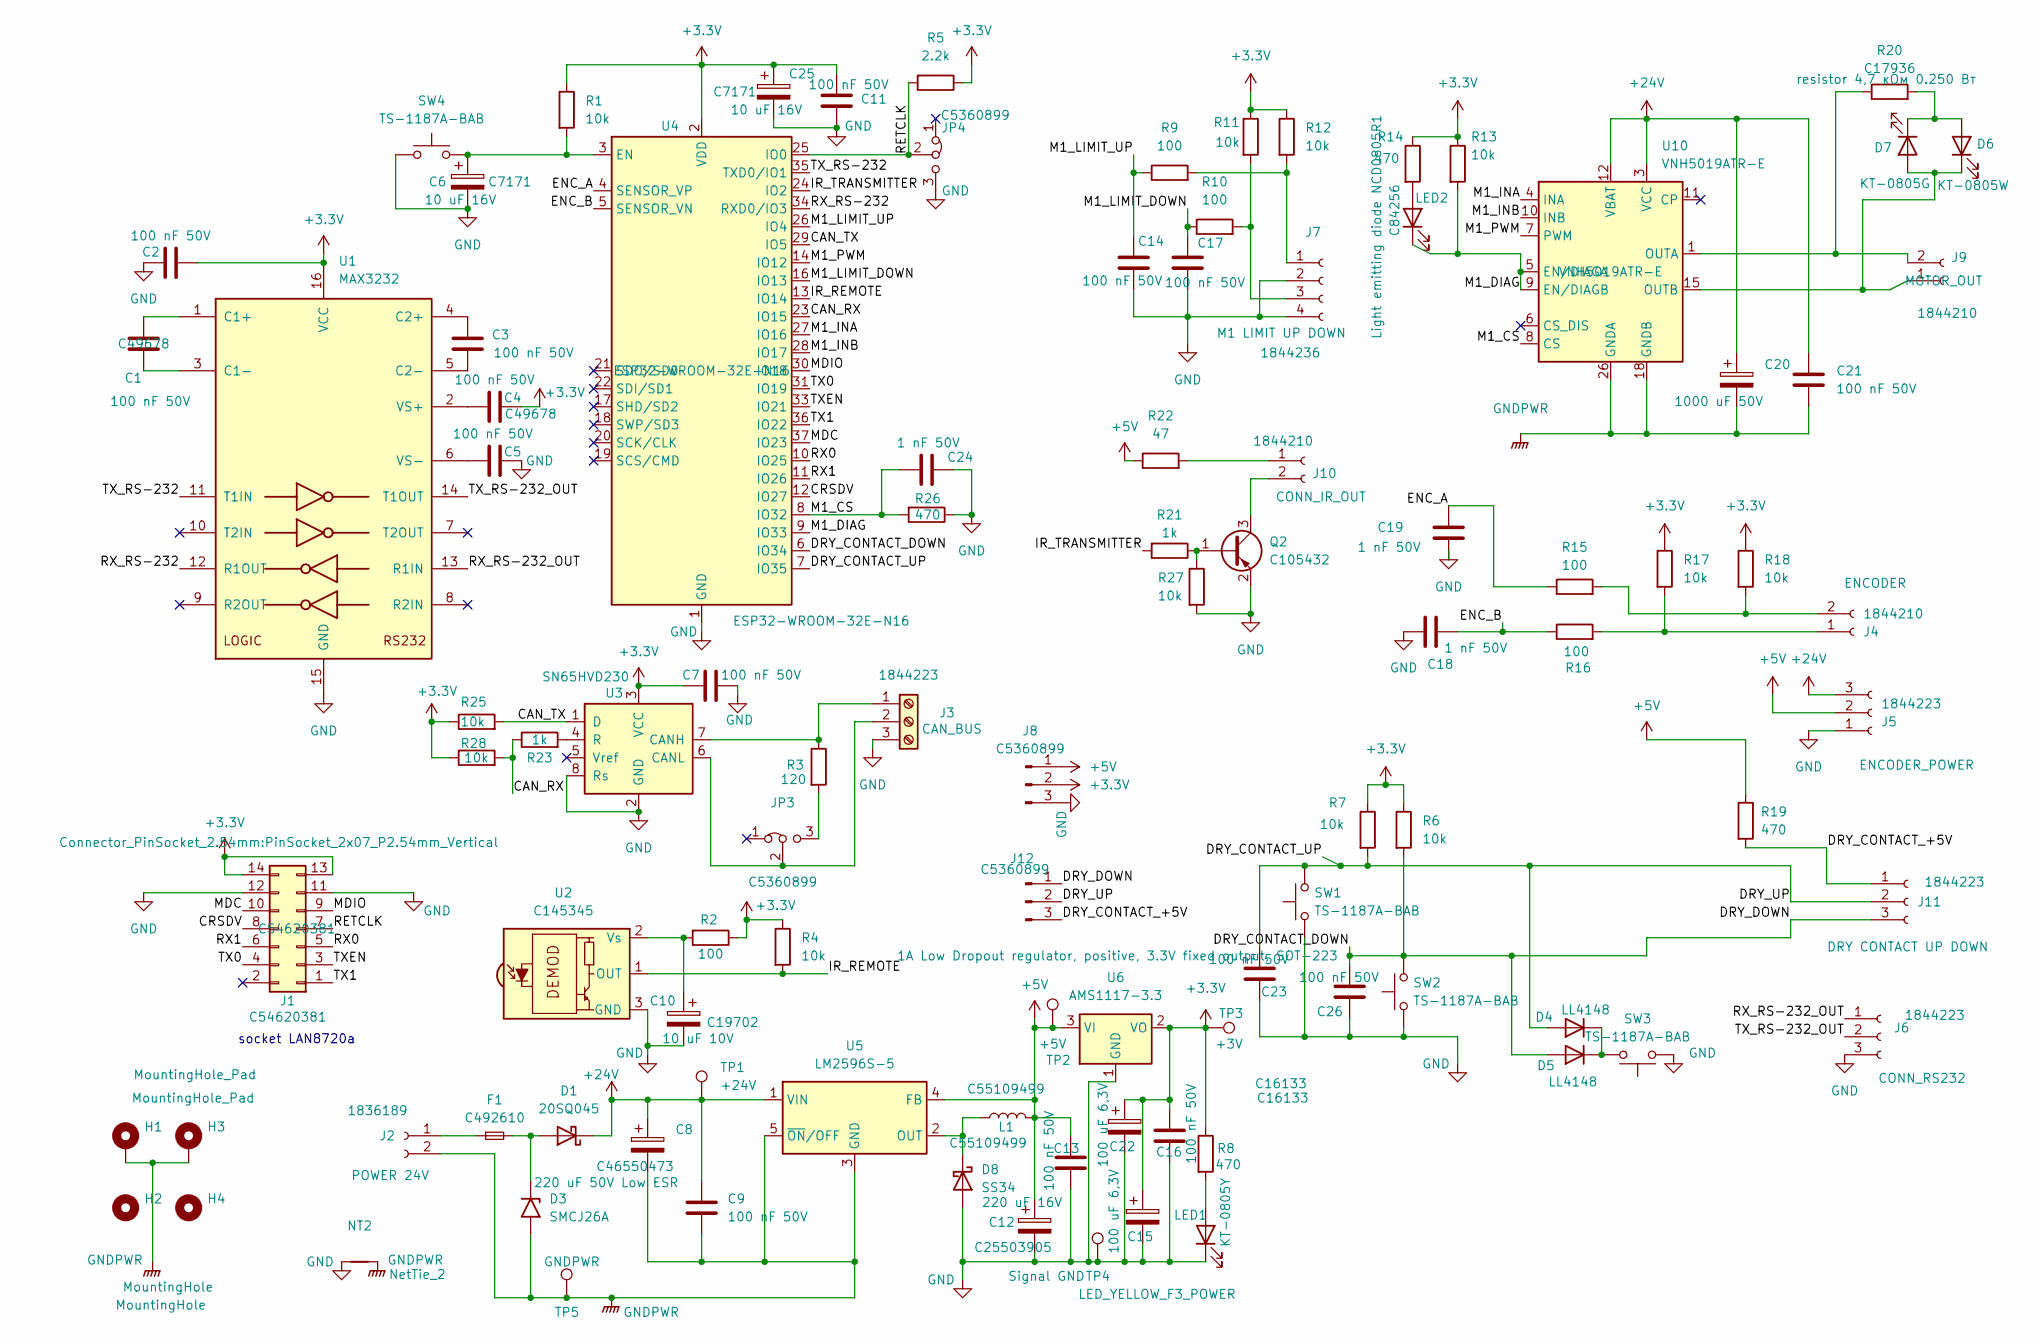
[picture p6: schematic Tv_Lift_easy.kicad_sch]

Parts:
C1, C2, C3, C4, C5, C7, C9, C11, C13, C14, C16, C17, C21, C23, C26: 100 nF 50V; C_0805_2012Metric
C6, C25: C7171; CP_EIA-3216-18_Kemet-A
C8: C46550473; CP_Elec_10x10
C10: C19702; C_0603_1608Metric
C12: C25503905; CP_Elec_6.3x7.7
C15, C22: C16133; CP_EIA-3528-21_Kemet-B_HandSolder
C18, C19, C24: 1 nF 50V; C_0805_2012Metric
C20: 1000 uF 50V; CP_Radial_D8.0mm_P3.50mm
D1: 20SQ045; D_DO-201AD_P15.24mm_Horizontal
D3: SMCJ26A; D_SMC
D4, D5: LL4148; D_MiniMELF
D6: KT-0805W; LED_0805_2012Metric
D7: KT-0805G; LED_0805_2012Metric
D8: SS34; D_SMA
F1: C492610; Fuseholder_XF-506P_mini_blade_C492610
H1, H3: MountingHole_Pad; MountingHole_2.7mm_M2.5_Pad_Via
H2, H4: MountingHole; MountingHole_2.7mm_M2.5_Pad_Via
J1: C54620381; PinSocket_2x07_P2.54mm_Vertical
J2: 1836189; PhoenixContact_MC_1,5_2-G-5.08_1x02_P5.08mm_Horizontal
J3, J5, J6, J11: 1844223; PhoenixContact_MC_1,5_3-G-3.5_1x03_P3.50mm_Horizontal
J4, J9, J10: 1844210; PhoenixContact_MC_1,5_2-G-3.5_1x02_P3.50mm_Horizontal
J7: 1844236; PhoenixContact_MC_1,5_4-G-3.5_1x04_P3.50mm_Horizontal
J8, J12: C5360899; PinHeader_1x03_P2.54mm_Vertical
JP3, JP4: C5360899; PinHeader_1x03_P2.54mm_Vertical
L1: C55109499; L_APV_ANR6045
LED1: KT-0805Y; LED_0805_2012Metric
LED2: C84256; LED_0805_2012Metric
NT2: NetTie_2; NetTie-2_THT_Pad1.0mm
Q2: C105432; SOT-23
R1, R4, R6, R7, R11, R12, R13, R17, R18, R25, R27, R28: 10k; R_0805_2012Metric
R2, R9, R10, R15, R16: 100; R_0805_2012Metric
R3: 120; R_0805_2012Metric
R5: 2.2k; R_0805_2012Metric
R8, R14, R19, R26: 470; R_0805_2012Metric
R20: C17936; R_1206_3216Metric
R21, R23: 1k; R_0805_2012Metric
R22: 47; R_1206_3216Metric
SW1, SW2, SW3, SW4: TS-1187A-BAB; SW_Push_1P1T_XKB_TS-1187A
TP1: +24V; TestPoint_Pad_D2.0mm
TP2: +5V; TestPoint_Pad_D2.0mm
TP3: +3V; TestPoint_Pad_D2.0mm
TP4: Signal GND; TestPoint_Pad_D2.0mm
TP5: GNDPWR; TestPoint_Pad_D2.0mm
U1: MAX3232; SOIC-16_3.9x9.9mm_P1.27mm
U2: C145345; Vishay_MOLD-3Pin
U3: SN65HVD230; SOIC-8_3.9x4.9mm_P1.27mm
U4: ESP32-WROOM-32E-N16; ESP32-WROOM-32
U5: LM2596S-5; TO-263-5_TabPin3
U6: AMS1117-3.3; SOT-223-3_TabPin2
U10: VNH5019ATR-E; ST_MultiPowerSO-30

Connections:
+3.3V: C2.2, C4.2, C7.1, C11.1, C15.1, C16.1, C22.1, C25.1, J1.13, J1.14, J8.2, R1.1, R2.1, R4.1, R5.1, R6.1, R7.1, R8.1, R11.1, R12.1, R13.1, R14.1, R17.1, R18.1, R25.1, R28.1, TP3.1 (1_1), U1.16 (VCC), U3.3 (VCC), U4.2 (VDD), U6.2 (VO)
+5V: C12.1, C13.1, J5.2, J8.1, L1.2, R19.1, R22.1, TP2.1 (1_1), U5.4 (FB), U6.3 (VI)
+24V: C8.1, C9.1, C20.1, C21.1, D1.1 (K), J5.3, TP1.1 (1_1), U5.1 (VIN), U10.3 (VCC), U10.12 (VBAT), U10.13 (VCC), U10.23 (VCC), U10.31 (VCC)
/CAN_RX: R23.1, R28.2, U4.23 (IO15)
/CAN_TX: R25.2, U3.1 (D), U4.29 (IO5)
/CRSDV: J1.8, U4.12 (IO27)
/DRY_CONTACT_+5V: J11.1, J12.3, R19.2
/DRY_CONTACT_DOWN: C26.1, D5.2 (A), J11.3, J12.1, R6.2, SW2.2, U4.6 (IO34)
/DRY_CONTACT_UP: C23.1, D4.2 (A), J11.2, J12.2, R7.2, SW1.2, U4.7 (IO35)
/ENC_A: C19.1, R15.1, U4.4 (SENSOR_VP)
/ENC_B: C18.2, R16.1, U4.5 (SENSOR_VN)
/IR_REMOTE: R4.2, U2.1 (OUT), U4.13 (IO14)
/IR_TRANSMITTER: R21.2, U4.24 (IO2)
/M1_CS: C24.2, R26.2, U4.8 (IO32), U10.8 (CS)
/M1_DIAG: LED2.1 (K), R13.2, U4.9 (IO33), U10.5 (EN/DIAGA), U10.9 (EN/DIAGB)
/M1_INA: U4.27 (IO16), U10.4 (INA)
/M1_INB: U4.28 (IO17), U10.10 (INB)
/M1_LIMIT_DOWN: C17.1, R10.1, U4.16 (IO13)
/M1_LIMIT_UP: C14.1, R9.1, U4.26 (IO4)
/M1_PWM: U4.14 (IO12), U10.7 (PWM)
/MDC: J1.10, U4.37 (IO23)
/MDIO: J1.9, U4.30 (IO18)
/RETCLK: J1.7, JP4.2 (C), R5.2, U4.25 (IO0)
/RX0: J1.5, U4.10 (IO25)
/RX1: J1.6, U4.11 (IO26)
/RX_RS-232: U1.12 (R1OUT), U4.34 (RXD0/IO3)
/RX_RS-232_OUT: J6.1, U1.13 (R1IN)
/TX0: J1.4, U4.31 (IO19)
/TX1: J1.1, U4.36 (IO22)
/TXEN: J1.3, U4.33 (IO21)
/TX_RS-232: U1.11 (T1IN), U4.35 (TXD0/IO1)
/TX_RS-232_OUT: J6.2, U1.14 (T1OUT)
GND: C2.1, C5.2, C6.2, C7.2, C10.2, C11.2, C12.2, C13.2, C14.2, C15.2, C16.2, C17.2, C18.1, C19.2, C22.2, C23.2, C24.1, C25.2, C26.2, D8.2 (A), J1.11, J1.12, J3.3, J5.1, J6.3, J7.2, J7.4, J8.3, JP4.3 (B), LED1.1 (K), NT2.1, Q2.2 (E), R26.1, R27.2, SW1.1, SW2.1, SW3.1, SW4.1, TP4.1 (1_1), U1.15 (GND), U2.3 (GND), U3.2 (GND), U3.8 (Rs), U4.1 (GND), U4.15 (GND), U4.38 (GND), U4.39 (GND), U6.1 (GND)
GNDPWR: C8.2, C9.2, C20.2, C21.2, D3.2 (A2), H1.1 (1_1), H3.1 (1_1), J2.2, NT2.2, TP5.1 (1_1), U5.3 (GND), U5.5 (~ON/OFF), U10.18 (GNDB), U10.19 (GNDB), U10.20 (GNDB), U10.26 (GNDA), U10.27 (GNDA), U10.28 (GNDA)
unnamed: D1.2 (A), D3.1 (A1), F1.2
unnamed: D4.1 (K), D5.1 (K), SW3.2
unnamed: D6.2 (A), D7.1 (K), R20.2
unnamed: D6.1 (K), D7.2 (A), J9.1 (M+), U10.15 (OUTB), U10.16 (OUTB), U10.21 (OUTB), U10.32 (OUTB)
unnamed: D8.1 (K), L1.1, U5.2 (OUT)
unnamed: F1.1, J2.1
unnamed: J3.1, R3.1, U3.7 (CANH)
unnamed: J3.2, JP3.2 (C), U3.6 (CANL)
unnamed: J4.1, R16.2, R17.2
unnamed: J4.2, R15.2, R18.2
unnamed: J7.1, R9.2, R12.2
unnamed: J7.3, R10.2, R11.2
unnamed: J9.2 (M-), R20.1, U10.1 (OUTA), U10.25 (OUTA), U10.30 (OUTA), U10.33 (OUTA)
unnamed: J10.1, R22.2
unnamed: J10.2, Q2.3 (C)
unnamed: JP3.3 (B), R3.2
unnamed: LED1.2 (A), R8.2
unnamed: LED2.2 (A), R14.2
unnamed: Q2.1 (B), R21.1, R27.1
unnamed: C1.1, U1.1 (C1+)
unnamed: C1.2, U1.3 (C1-)
unnamed: C3.1, U1.4 (C2+)
unnamed: C3.2, U1.5 (C2-)
unnamed: C4.1, U1.2 (VS+)
unnamed: C5.1, U1.6 (VS-)
unnamed: C10.1, R2.2, U2.2 (Vs)
unnamed: R23.2, U3.4 (R)
unnamed: C6.1, R1.2, SW4.2, U4.3 (EN)

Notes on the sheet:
socket LAN8720a

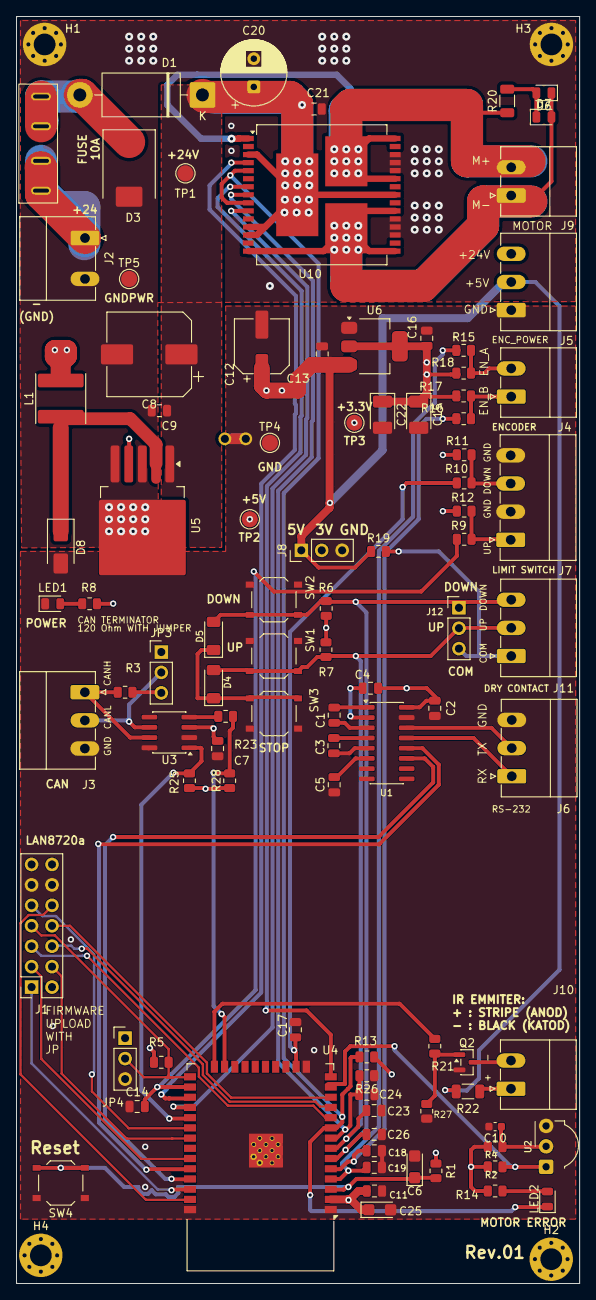
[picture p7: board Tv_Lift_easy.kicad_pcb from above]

Board: 4 copper layers, 70.0 x 157.5 mm, 100 parts (0 on the bottom side), 62 nets.

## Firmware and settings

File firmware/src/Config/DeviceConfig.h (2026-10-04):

#pragma once

#include <stdint.h>
#include <Preferences.h>

namespace DeviceConfig
{
// Версия прошивки
inline const char* VERSION = "1.2.3"; // Обновите версию при каждом изменении прошивки
    
// Единый источник дефолтных значений для сброса и инициализации
namespace Defaults {
    // --- КОНФИГУРАЦИЯ УСТАНОВКИ ЛИФТА (ПЛАТЫ УПРАВЛЕНИЯ) ---    
    constexpr uint8_t MOUNT_TYPE = 1; // 0 = FLOOR, 1 = CEILING, 2 = WALL  Настройка типа лифта (по умолчанию CEILING, т.к. чаще всего используется потолочный вариант)
    constexpr bool IS_MASTER = true; // true = master, false = slave
    constexpr uint8_t NODE_ID = 1; // Идентификатор узла (для master/slave конфигурации, по умолчанию 1) для мультимоторных систем, где несколько плат управляют разными моторами лифта. Каждый узел должен иметь уникальный идентификатор (1, 2, 3 и т.д.).
    constexpr bool DEBUG_ENABLED = true; // Разрешить/запретить вывод отладочных сообщений (по умолчанию false)

    // --- СКОРОСТЬ МОТОРА ---
    constexpr uint8_t MOTOR_SPEED = 200; // range 0-255 
    constexpr uint8_t SOFT_START_MIN_PWM = 10;  // Минимальный ШИМ, при котором мотор начинает крутиться
    constexpr uint32_t SOFT_START_STEP_MS = 100;  // Интервал увеличения ШИМ (мс)
    constexpr uint8_t SOFT_START_STEP_PWM = 10;  // Шаг прибавки ШИМ

    // --- НАСТРОЙКИ ТОКА И ЗАЩИТЫ --- ПРИМЕР! (требуется проверка и калибровка под конкретный мотор и драйвер) !!!
    constexpr float CURRENT_SENSOR_SENSITIVITY = 0.5f;  // Чувствительность датчика тока (Ампер на Вольт) - необходимо уточнить при калибровке под конкретный мотор и драйвер
    constexpr float CURRENT_SENSOR_OFFSET_V = 0.0f;     // Напряжение при 0А 
    constexpr float START_CURRENT_TIMEOUT_MS = 300; // Время превышения максимального тока при старте (мс)
    constexpr float MAX_MOTOR_CURRENT_AMPS = 2.0f;       // Порог тока (Ампер)
    constexpr uint32_t OVERCURRENT_TIMEOUT_MS = 300;    // Время превышения до аварии (мс)

    // Максимальное время работы мотора для каждого направления
    constexpr uint32_t MAX_FORWARD_TIME_MS = 60000; // 60 секунд на подъем (вперед) (мс)
    constexpr uint32_t MAX_REVERSE_TIME_MS = 60000; // 60 секунд на спуск (назад) (мс)

    // Время добега после срабатывания концевика в мсек. 0 = остановить мотор сразу.
    constexpr uint32_t FORWARD_LIMIT_RUN_ON_MS = 0; 
    constexpr uint32_t REVERSE_LIMIT_RUN_ON_MS = 0; 
    
    // Конфигурация счетчика оборотов мотора 
    constexpr uint32_t MAX_LIFT_ENCODER_TICKS = 0; // 

    // Настройки управления лифтом инфракрасными пультом
    constexpr uint32_t IR_CODE_UP     = 0x11EEA857; 
    constexpr uint32_t IR_CODE_DOWN   = 0x11EE6897; 
    constexpr uint32_t IR_CODE_STOP   = 0x11EE9867; 
    constexpr uint32_t IR_CODE_REPEAT = 0xFFFFFFFF; // Код зажатия/повтора кнопки

    // Адрес для обновления прошивки OTA 
    const char OTA_URL[] = "http://192.168.88.33:3000/firmware/version.json"; // URL для проверки обновлений прошивки (можно указать локальный сервер или внешний URL)
    constexpr uint32_t OTA_UPDATE_INTERVAL_MS = 60000; // Интервал проверки обновлений (мс)

    // --- НАСТРОЙКИ ЛОКАЛЬНОГО MQTT (Home Assistant) ---
    constexpr bool LOCAL_MQTT_ENABLED = true;
    const char LOCAL_MQTT_SERVER[] = "192.168.1.100";
    constexpr uint16_t LOCAL_MQTT_PORT = 1883;
    const char LOCAL_MQTT_USER[] = "";
    const char LOCAL_MQTT_PASS[] = "";
    constexpr bool LOCAL_MQTT_HA_DISCOVERY = true;

    // --- НАСТРОЙКИ ОБЛАЧНОГО MQTT (VPS Telemetry) ---
    constexpr bool CLOUD_MQTT_ENABLED = true;
    const char CLOUD_MQTT_SERVER[] = "vps.yourdomain.com";
    constexpr uint16_t CLOUD_MQTT_PORT = 1883;
    const char CLOUD_MQTT_TOKEN[] = "SECRET_TOKEN";
   
}
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

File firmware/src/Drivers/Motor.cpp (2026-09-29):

#include "Motor.h"
#include <Arduino.h>
#include <cstring>
#include "../Config/BoardConfig.h"
#include "../Config/DeviceConfig.h"
#include "Logger/Logger.h"
#include <soc/gpio_struct.h>

std::atomic<bool> Motor::s_hardwareFault{false}; 
std::atomic<int32_t> Motor::s_encoderPosition{0};

Motor::Motor()
    : m_state(MotorState::STOPPED)
{
}

void Motor::init()
{
    pinMode(BoardConfig::MOTOR1_INA, OUTPUT);
    pinMode(BoardConfig::MOTOR1_INB, OUTPUT);
    pinMode(BoardConfig::MOTOR1_DIAG, INPUT_PULLUP);
    pinMode(BoardConfig::IR_TRANSMITTER_PIN, OUTPUT);
    digitalWrite(BoardConfig::IR_TRANSMITTER_PIN, LOW);

    pinMode(BoardConfig::ENC_A, INPUT);
    pinMode(BoardConfig::ENC_B, INPUT);
    pinMode(BoardConfig::MOTOR1_CURR_SENS, INPUT);
    analogReadResolution(12);

    // Инициализация PWM (совместимо с ESP32 Core v3.x)
    ledcAttach(
        BoardConfig::MOTOR1_PWM,
        PWM_FREQUENCY,
        PWM_RESOLUTION
    );
    
    stop();

    if (digitalRead(BoardConfig::MOTOR1_DIAG) == LOW) 
    {
        emergencyStopFromISR();
    }
    
    attachInterrupt(
        digitalPinToInterrupt(BoardConfig::MOTOR1_DIAG),
        Motor::emergencyStopFromISR,
        FALLING
    );

    attachInterrupt(
        digitalPinToInterrupt(BoardConfig::ENC_A),
        Motor::encoderISR,
        RISING
    );

    setMaxEncoderTicks(DeviceConfig::MAX_LIFT_ENCODER_TICKS); 
}

void IRAM_ATTR Motor::emergencyStopFromISR()
{
    // Мгновенный сброс управляющих выводов за 1 такт процессора через прямой доступ к регистру
    uint32_t lowMask = 0;
    if (BoardConfig::MOTOR1_INA < 32) lowMask |= (1UL << BoardConfig::MOTOR1_INA);
    if (BoardConfig::MOTOR1_INB < 32) lowMask |= (1UL << BoardConfig::MOTOR1_INB);
    if (BoardConfig::MOTOR1_PWM < 32) lowMask |= (1UL << BoardConfig::MOTOR1_PWM);

    if (lowMask > 0) GPIO.out_w1tc = lowMask;

    s_hardwareFault.store(true, std::memory_order_relaxed);
}

void Motor::update() {
    const uint32_t now = millis();

    // 1. Делаем СТРОГО ОДНО чтение ADC за тик
    float currentAmps = readCurrentSensor();

    if (m_state == MotorState::STOPPED) {
        m_cachedCurrentAmps = 0.0f; // При простое отдаем честные 0A
    } else {
        m_cachedCurrentAmps = currentAmps; // Записываем реальное значение в кэш
        checkOvercurrent(currentAmps);     // Проверка перегрузки по току
    }

    // 1.1 Блокировка при аварии
    if (isEmergency()) {
        if (m_targetState != MotorState::STOPPED || m_state != MotorState::STOPPED) {
            Logger::warning("Motor action ignored: Active EMERGENCY condition!");
            stop(); 
        }
        return; 
    }

    // 2. Dead Time и запуск движения
    if (m_targetState != MotorState::STOPPED && m_state != m_targetState) {
        bool isDeadTimePassed = (m_deadTimeStartMs == 0) || 
                                ((now - m_deadTimeStartMs) >= BoardConfig::MOTOR_DEAD_TIME_MS);

        if (isDeadTimePassed) {
            m_moveStartMs = now;
            m_overcurrentStartMs = 0;

            if (m_targetState == MotorState::FORWARD) {
                digitalWrite(BoardConfig::MOTOR1_INB, LOW);
                digitalWrite(BoardConfig::MOTOR1_INA, HIGH);
                m_state = MotorState::FORWARD;
                Logger::debug("Motor FORWARD");
            } 
            else if (m_targetState == MotorState::REVERSE) {
                digitalWrite(BoardConfig::MOTOR1_INA, LOW);
                digitalWrite(BoardConfig::MOTOR1_INB, HIGH);
                m_state = MotorState::REVERSE;
                Logger::debug("Motor REVERSE");
            }

            m_currentPwm = DeviceConfig::SOFT_START_MIN_PWM;
            ledcWrite(BoardConfig::MOTOR1_PWM, m_currentPwm);
            m_lastRampMs = now;

            Logger::debug("Motor STARTED successfully.");
        }
        return; 
    }

    // 3. Управление в процессе движения
    if (m_state == MotorState::FORWARD || m_state == MotorState::REVERSE) {

        // Ограничения по энкодеру
        if (m_maxEncoderTicks > 0) {
            int32_t currentPos = getEncoderPosition();

            if (m_state == MotorState::FORWARD && currentPos >= m_maxEncoderTicks) {
                stop();
                Logger::warning("Motor STOPPED: Reached MAX Encoder Soft Limit!");
                return;
            }

            if (m_state == MotorState::REVERSE && currentPos <= 0) {
                stop();
                Logger::warning("Motor STOPPED: Reached MIN (0) Encoder Soft Limit!");
                return;
            }
        }

        // Плавный разгон (Soft Start)
        if (m_currentPwm < DeviceConfig::MOTOR_SPEED) {
            if (now - m_lastRampMs >= DeviceConfig::SOFT_START_STEP_MS) {
                m_lastRampMs = now;
                int nextPwm = m_currentPwm + DeviceConfig::SOFT_START_STEP_PWM;
                if (nextPwm > DeviceConfig::MOTOR_SPEED) nextPwm = DeviceConfig::MOTOR_SPEED;
                if (nextPwm > 255) nextPwm = 255;
                
                m_currentPwm = (uint8_t)nextPwm;
                ledcWrite(BoardConfig::MOTOR1_PWM, m_currentPwm);
            }
        }

        if (DeviceConfig::DEBUG_ENABLED) {
            if (now - m_lastCurrentLogMs >= 500) {
                m_lastCurrentLogMs = now;
                Serial.println(getCurrentAmps(), 2); 
            }
        }
    }
}

float Motor::getCurrentAmps() {
    return m_cachedCurrentAmps;
}

float Motor::readCurrentSensor() {
    uint16_t newSample = analogRead(BoardConfig::MOTOR1_CURR_SENS);

    // Обновляем кольцевой буфер (Moving Average)
    m_adcSum -= m_adcBuffer[m_adcIndex];
    m_adcBuffer[m_adcIndex] = newSample;
    m_adcSum += newSample;
    m_adcIndex = (m_adcIndex + 1) % ADC_SAMPLES_COUNT;

    float avgAdc = (float)m_adcSum / ADC_SAMPLES_COUNT;
    float voltageV = (avgAdc * 3.3f) / 4095.0f;
    float netVoltageV = voltageV - DeviceConfig::CURRENT_SENSOR_OFFSET_V;
    
    if (netVoltageV <= 0.0f) return 0.0f;

    return netVoltageV / DeviceConfig::CURRENT_SENSOR_SENSITIVITY;
}

void Motor::checkOvercurrent(float currentAmps) {
    const uint32_t now = millis();

    bool isStarting = (now - m_moveStartMs < DeviceConfig::startCurrentTimeoutMs);
    float activeLimit = isStarting ? (DeviceConfig::maxMotorCurrentAmps * 1.5f) 
                                   : DeviceConfig::maxMotorCurrentAmps;

    if (currentAmps >= activeLimit) {
        if (m_overcurrentStartMs == 0) {
            m_overcurrentStartMs = now;
        } 
        else if (now - m_overcurrentStartMs >= DeviceConfig::overcurrentTimeoutMs) {
            stop();

            m_isEmergency = true;
            m_isOvercurrentFault = true;
            setOvercurrentLED(true); 

            char logBuf[128];
            snprintf(logBuf, sizeof(logBuf), "OVERCURRENT FAULT! Current: %.2fA (Limit: %.2fA)", 
                     currentAmps, activeLimit);
            Logger::error(logBuf);
        }
    } else {
        m_overcurrentStartMs = 0;
    }
}
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

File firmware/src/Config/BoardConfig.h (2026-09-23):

#pragma once

#include <stdint.h>

namespace BoardConfig
{
    // Board name and revision
    constexpr char BOARD_NAME[] = "TV Lift Controller";
    constexpr char BOARD_REVISION[] = "REV_A";

    // Частота процессора ESP32
    constexpr uint32_t CPU_FREQUENCY_MHZ = 240;

    // -------------------------
    // Parametrs
    // -------------------------

    constexpr uint8_t MOTOR_DEFAULT_SPEED = 180; // range 0-255
    constexpr uint32_t MOTOR_DEAD_TIME_MS = 50; // Пауза при смене направления (мс)

    // -------- PinOut --------

    // -------------------------
    // Motor 
    // -------------------------

    constexpr uint8_t MOTOR1_INA = 16;
    constexpr uint8_t MOTOR1_INB = 17;
    constexpr uint8_t MOTOR1_PWM= 12; // WARNING - This pin is used by the ESP32 for bootstrapping. Using it may cause issues during boot.
    constexpr uint8_t MOTOR1_DIAG = 33; // пин DIAG с драйвера мотора, который сигнализирует о неисправности драйвера
    constexpr uint8_t MOTOR1_CURR_SENS = 32; //пин для измерения тока мотора с выхода драйвера мотора

    // -------------------------
    // ENCODERS
    // -------------------------

    constexpr uint8_t ENC_A = 36; // Physical pin 4 of ESP32-WROOM-32D
    constexpr uint8_t ENC_B = 39; // Physical pin 5 of ESP32-WROOM-32D

    // -------------------------
    // Dry contacts
    // -------------------------

    constexpr uint8_t DRY_CONTACT_DOWN_PIN = 34; 
    constexpr uint8_t DRY_CONTACT_UP_PIN = 35;

    // -------------------------
    // Limit switches
    // -------------------------

    constexpr uint8_t LIMIT_SWITCH_DOWN_PIN = 13;
    constexpr uint8_t LIMIT_SWITCH_UP_PIN = 4;

    // -------------------------
    // Communication
    // -------------------------

    constexpr uint8_t UART_TX_PIN = 1;
    constexpr uint8_t UART_RX_PIN = 3;

    constexpr uint8_t CAN_TX_PIN = 5; // WARNING - This pin is used by the ESP32 for bootstrapping. Using it may cause issues during boot.
    constexpr uint8_t CAN_RX_PIN = 15; // WARNING - This pin is used by the ESP32 for bootstrapping. Using it may cause issues during boot.

    constexpr uint8_t IR_RECEIVER_PIN = 14;
    constexpr uint8_t IR_TRANSMITTER_PIN = 2;

    // -------------------------
    // Ethernet
    // -------------------------

    constexpr uint8_t ETH_RETCLK = 0;
    constexpr uint8_t ETH_MDC = 23;
    constexpr uint8_t ETH_MDIO = 18;
    constexpr uint8_t ETH_RX1 = 26;
    constexpr uint8_t ETH_TX1 = 22;
    constexpr uint8_t ETH_CRS_DV = 27;
    constexpr uint8_t ETH_TX_EN = 21;
    constexpr uint8_t ETH_RX0 = 25;
    constexpr uint8_t ETH_TX0 = 19;




    
}

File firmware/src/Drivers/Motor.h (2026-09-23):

#pragma once

#include <Arduino.h>
#include <atomic>

enum class MotorState
{
    STOPPED,
    FORWARD,
    REVERSE,
    DEAD_TIME
};

class Motor
{
public:
    Motor();

    void init();
    void update();
    void forward();
    void reverse();
    void stop();

    MotorState getState() const { return m_state; }

    void setSpeed(uint8_t speed);
    uint8_t getSpeed();
    
    // Энкодер
    int32_t getEncoderPosition() const;
    int32_t getMaxEncoderTicks() const;
    void setMaxEncoderTicks(int32_t maxTicks);
    void resetEncoder();

    // Защита и ток
    IRAM_ATTR static void emergencyStopFromISR();
    float getCurrentAmps();

    // ЕДИНЫЙ ФЛАГ АВАРИИ ДЛЯ ВНЕШНИХ МОДУЛЕЙ (Elevator)
    bool isEmergency() const { return m_isEmergency || s_hardwareFault.load(std::memory_order_relaxed); }

private:
    MotorState m_state = MotorState::STOPPED;
    MotorState m_targetState = MotorState::STOPPED;

    static constexpr uint32_t PWM_FREQUENCY = 20000;
    static constexpr uint8_t  PWM_RESOLUTION = 8;

    uint8_t  m_currentPwm{0};
    uint32_t m_lastRampMs{0};
    uint32_t m_deadTimeStartMs{0};
    uint32_t m_lastCurrentLogMs = 0;
    
    // Защита по току
    uint32_t m_moveStartMs = 0;
    uint32_t m_overcurrentStartMs = 0;
    uint32_t m_firstOvercurrentMs = 0;
    uint8_t  m_overcurrentResetCount = 0; // Сбросов токовой защиты

    // Паттерн 3х STOP за 2 сек
    uint32_t m_stopClickTimes[3] = {0, 0, 0};
    uint8_t  m_stopClickIndex = 0;

    // Энкодер
    static std::atomic<int32_t> s_encoderPosition; 
    static void IRAM_ATTR encoderISR();
    int32_t m_maxEncoderTicks = 0;
   
    // Флаги аварий
    static std::atomic<bool> s_hardwareFault; // Аппаратная авария по DIAG (от ISR)
    bool m_isEmergency = false;               // Общий флаг аварии (в т.ч. по току)
    bool m_isOvercurrentFault = false;        // Маркер, что авария именно токовая (для сброса)

    void setOvercurrentLED(bool enable);
    void checkOvercurrent(float);
    float readCurrentSensor();
    void registerStopClick();
    bool tryClearFault();

    // переменные вычисления силы тока
    static constexpr uint8_t ADC_SAMPLES_COUNT = 8;
    uint16_t m_adcBuffer[ADC_SAMPLES_COUNT] = {0};
    uint32_t m_adcSum = 0;
    uint8_t m_adcIndex = 0;
    float m_cachedCurrentAmps = 0.0f;
};

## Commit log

2026-07-22 add file for prodaction board
    [controller_Tv_Lift-B_Cu.gbr, controller_Tv_Lift-B_Mask.gbr, controller_Tv_Lift-B_Paste.gbr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]
2026-07-22 add kicad files
    [controller_Tv_Lift-B_Cu.gbr, controller_Tv_Lift-B_Mask.gbr, controller_Tv_Lift-B_Paste.gbr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]
2026-07-22 fix schema ( fuse + annotation)
    [controller_Tv_Lift.kicad_pcb]
2026-07-22 fix annotations on sockets output
    [controller_Tv_Lift.kicad_pcb, controller_Tv_Lift.kicad_sch]
2026-08-04 change inpit diod
    [controller_Tv_Lift.kicad_sch]
2026-08-04 add button reset
    [controller_Tv_Lift.kicad_pcb, controller_Tv_Lift.kicad_sch]
2026-08-04 add ground poligon on bottom layer
    [controller_Tv_Lift.kicad_pcb]
2026-08-04 change diod suspressor
    [controller_Tv_Lift.kicad_pcb, controller_Tv_Lift.kicad_sch]
2026-08-04 new file: hardware/TV_Lift_Kicad files/~controller_Tv_Lift.kicad_sch.lck
2026-08-05 add prodactions file
    [JLCMC_BOM_Template.xlsx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]
2026-08-07 fix bom list of connectors
    [bom.csv, controller_Tv_Lift.csv, controller_Tv_Lift.kicad_pcb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]
2026-08-08 done boardConfig.h
    [controller_Tv_Lift.kicad_sch]
2026-08-08 add Motor files
2026-08-09 add set motor speed
    [JLCMC_BOM_Template.xlsx]
2026-08-09 fix input manager: correct limit switch logic and remove unnecessary comments
    [controller_Tv_Lift.kicad_pcb, controller_Tv_Lift.kicad_sch]
2026-08-10 change capacitors on smd
    [controller_Tv_Lift.kicad_pcb, controller_Tv_Lift.kicad_sch]
2026-08-11 change pins dry contavt and limit switch and pwm
2026-08-11 fix piout after change done
    [controller_Tv_Lift.kicad_sch]
2026-08-11 change pin 2 and 5
    [JLCMC_BOM_Template.xlsx]
2026-08-12 finish pcb board change pins
    [bom_controller_Tv_Lift.csv, controller_Tv_Lift.kicad_pcb, controller_Tv_Lift.kicad_sch]
2026-08-13 fix run-on log
    [controller_Tv_Lift.kicad_pcb]
2026-08-13 add diagnostic motor driver fault from DIAG pin
2026-08-13 add option current sensor
    [controller_Tv_Lift.kicad_sch]
2026-08-14 fix overcurrent
    [controller_Tv_Lift.kicad_sch]
2026-08-14 add IR remote driver
2026-08-19 fix direction celing mount
    [DeviceConfig.h, Elevator.cpp, Motor.cpp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]
2026-08-19 fix split overcurrent and driver error . add reset overcurent
    [DeviceConfig.h, Elevator.cpp, Motor.cpp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]
2026-08-23 fix BOM file and pcb
    [bom.csv, bom_controller_Tv_Lift.csv, controller_Tv_Lift.csv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]
2026-08-27 rewrite BOM
    [BOM_controller_Tv_Lift.csv, bom.csv, controller_Tv_Lift.kicad_pcb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]
2026-08-27 add web status and fix iphone page
    [Elevator.cpp, WebManager.cpp]
2026-08-27 fix comand name for web
    [Elevator.cpp, WebManager.cpp]
2026-09-01 add dead time for motor and soft start
2026-09-01 add counter encoders and max opened value
2026-09-02 fix files structure the main project
    [BoardConfig.h, DeviceConfig.h, Elevator.cpp]
2026-09-02 тест ота
2026-09-03 fix config interface update
    [DeviceConfig.h, WebManager.cpp]
2026-09-03 тест
2026-09-03 fix save config over web
    [DeviceConfig.h]
2026-09-04 add current current in web interface
2026-09-04 add button default settinfs
2026-09-04 test web panel current view
2026-09-06 add deny update OTA if motor in action
2026-09-06 test OTA on action motor
2026-09-06 fix sourse CLI commadnd
    [ConsoleManager.cpp, Elevator.cpp]
2026-09-07 fix slow start and set motor speed over config
    [DeviceConfig.h, Elevator.cpp, Motor.cpp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]
2026-09-11 add newe fuse easy board version
    [BOM.csv, Tv_Lift_easy.kicad_pcb, Tv_Lift_easy.kicad_sch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]
2026-09-11 cosmetic fix config page ( annotation) and feractoring startUp wifi page
    [WebManager.cpp]
2026-09-11 fix web page with LAST IR CODE
    [DeviceConfig.h]
2026-09-19 fix bug with not work PWM after sometimes
    [Elevator.cpp, Motor.cpp]
2026-09-19 fix bug with not work PWM after sometimes ver 2
    [Elevator.cpp, Motor.cpp, Motor.h]
2026-09-19 fix motor jump after emerginci out
    [DeviceConfig.h, Elevator.cpp]
2026-09-23 rewrite motor and elevator
2026-09-23 module motor done
2026-09-27 fix wifi portal on english and fix debuonce limit switchers
    [DeviceConfig.h, InputManager.cpp, InputManager.h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]
2026-09-29 fix Motor::tryClearFault()
